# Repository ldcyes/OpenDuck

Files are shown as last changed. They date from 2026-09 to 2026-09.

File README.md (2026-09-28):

# OpenDuck 工程

**简体中文** | [English](README_EN.md)

本仓库整理 Microduck 的结构、电气、步态数值验证，以及 RK3576 驱动和训练适配源。**当前是工程仿真预发布，尚未通过实物制造与正常步速行走验收。**

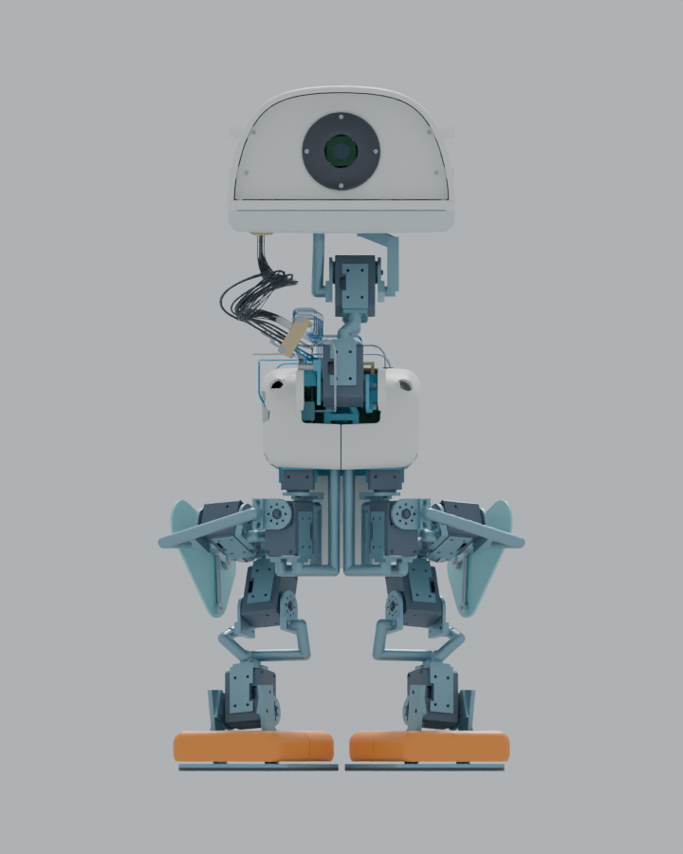
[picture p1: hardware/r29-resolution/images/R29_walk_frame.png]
OpenDuck R29 正视运动模型


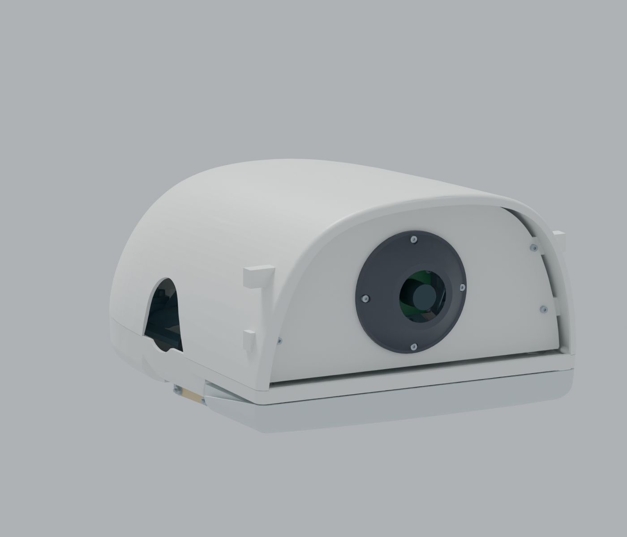
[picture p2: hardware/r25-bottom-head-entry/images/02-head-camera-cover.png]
头部摄像头前盖特写


**本次更新：[R29 干涉、线束与质量重算](hardware/r29-resolution/README.md) · [完整 Blender 与证据下载](https://github.com/ldcyes/OpenDuck/releases/tag/r29-r26-closure-candidate-20260929)。**

R29 将嘴部软件行程收至 0–10° 并修正下头壳；指定腿罩/电机配对在四条新质量慢速轨迹中的最低保守名义间隙下界为 11.407 mm。31 根线的防磨件和四工况动力学已补充，但嘴部闭合扭矩仍超过现行 0.05 Nm 结构限制，连续线束及制造公差尚无实物证明，**不能放行行走**。

沿用R25：31根头部导线改为底部接入，保留前盖与原外形比例；收拢活动线束并取消原侧面专用线孔。[底部走线特写](hardware/r25-bottom-head-entry/images/03-bottom-head-entry.png)。仍为工程候选，离散转头检查不代表连续运动或实物验收。

**历史四步回放：[R27：R26整机运动回放](hardware/r27-walk-replay/README.md)。** 使用已保存的195.44秒实际积分轨迹，逐帧驱动完整R26装配并复核覆盖件的刚体干涉增量；R26质量下的动力学和实物行走仍待验收。

**修复前干涉记录：[R28直接区间检查](hardware/r28-r26-interference/README.md)。** 两块新腿罩在四步轨迹的2,345组动态配对中没有新增穿透；最小保守间隙证明仅0.015 mm，制造公差未通过。旧头壳与嘴部在张嘴约8.75°后仍有真实相交。

**2026-09-24设计复核：[腿部比例与电机筛选](docs/proportion-study-20260924/README.md)。前期比较三种方案，现已采用A修改覆盖件；电机和腿长不变，实物步态未验收。**

[R24摄像头前盖](hardware/r24-head-front/README.md)与历史发布继续保留。

[R23合板支架、线束与热连接](hardware/r23-design/README.md)及其[完整工程](https://github.com/ldcyes/OpenDuck/releases/tag/r23-integrated-power-design-20260922)继续保留。

| 范围 | 早期基线（R23补充见上方入口） | 已有结果与边界 |
|---|---|---|
| 结构与装配 | R20 / R13.7 | 557件，名义质量4.195094 kg；72对参考窄/未证、34对实际名义接口仍保留 |
| 运动 | R21 / R13.8 | 实际身体侧倾与上头壳固定点横摆均减少约28.6%；慢速四步195.44 s；四种数值工况通过，原40%/30%目标未达到 |
| 电气 | R13原生板图 | 12种、13块；原规则DRC为0；额外启用忽略规则仍有43项警告；6块PCB、U2D2及相机待详细安装 |
| 驱动、交互和训练适配 | 已交付R8软件 | 有源码与历史测试；没有RK3576实机运行、GPU训练、实测BAM和批准权重；未完成R20/R21重新适配验收 |

## 从这里开始

- [直接下载完整装配、原始交付包和视频](https://github.com/ldcyes/OpenDuck/releases/tag/r13.8-simulation-20260913)：模型可独立打开；全部大文件保留原始内容，仅采用方便下载的英文文件名。
- [12种KiCad板、原理图及BOM入口](docs/pcb/原生电气设计入口.md)：每板均含项目文件、本地符号库与封装库。
- [PCB功能与主要器件](docs/pcb/01_全部PCB功能与主要器件.md)、[DRC和尺寸结论](docs/pcb/00_PCB检查与缩板结论.md)、[43项警告复核](docs/pcb/02_43项警告逐对象复核.md)。
- [结构修订和完整装配说明](docs/structure-r20/00_修复结果与查看说明.md)、[减摆结果](docs/motion-r21/00_减摆结果与查看说明.md)、[模型与视频查看方法](docs/motion-r21/02_模型与视频查看说明.md)。
- [软件、部署和训练真实入口](docs/software.md)、[复算与来源校验](docs/reproduction.md)、[来源和许可](NOTICE.md)。

## 下载内容

| 文件 | 内容 | 大小（十进制MB） |
|---|---|---:|
| [R13.7结构包](https://github.com/ldcyes/OpenDuck/releases/download/r13.8-simulation-20260913/R13.7-structure-gait.zip) | 结构、图纸、装配模型、沿用源快照和验证结果 | 730.83 |
| [R13.8步态更新包](https://github.com/ldcyes/OpenDuck/releases/download/r13.8-simulation-20260913/R13.8-reduced-sway.zip) | 新步态、四工况结果、减摆对照、更新代码与原始索引 | 603.51 |
| [PCB完整检查包](https://github.com/ldcyes/OpenDuck/releases/download/r13.8-simulation-20260913/PCB-R13-review.zip) | 12种原生板图、BOM、本地库与检查证据 | 1.99 |
| [完整Blender装配](https://github.com/ldcyes/OpenDuck/releases/download/r13.8-simulation-20260913/Microduck-R21-actual-comparison.blend) | 内含全部零件和实际运动，可直接打开 | 66.22 |
| [实际四步视频](https://github.com/ldcyes/OpenDuck/releases/download/r13.8-simulation-20260913/R21-four-steps-24x.mp4) | 约24倍播放速度；原始物理时间195.44 s | 1.14 |
| [同阶段对照视频](https://github.com/ldcyes/OpenDuck/releases/download/r13.8-simulation-20260913/R20-R21-phase-comparison.mp4) | 对齐参考阶段的R20/R21可视化 | 1.45 |

大小和SHA256见 [release-assets.json](release-assets.json) 与 [SHA256SUMS.txt](SHA256SUMS.txt)。GitHub自动生成的“Source code”压缩包只包含本仓库，不包含上述大型交付包。

## 仓库布局

| 目录 | 用途 |
|---|---|
| [hardware/kicad](hardware/kicad) | R13原生板图及本地库，201个文件保留原字节 |
| [docs](docs) | 适合GitHub浏览的说明、图和PCB复核 |
| [software/r8](software/r8) | 已交付R8驱动、交互、训练适配、相机/VLA源码与原验证记录 |
| [reference/work](reference/work) | R20/R21精选原始脚本、核心结果和两版实际轨迹；完整依赖在Release |
| [provenance](provenance) | 原始来源索引、复制哈希和文档路径转换记录 |
| [tools](tools) | 便携的仓库/附件校验和减摆复算入口 |
| [licenses](licenses) | 按来源分别保留的许可及上游说明 |

## 当前限制

正式四步从已经检查的新准备站姿开始；站姿过渡候选没有同等级完整验证。没有完成正常步速、温升、低电量持续扭矩或实物验收，也没有据此放行所有装配间隙。待安装件已有估算质量，实际安装时须替换，不能重复计重。

R8运行时的嘴部限位已按R29改为10°，旧标定/命令绑定会失效；其余硬件、策略及标定仍须重新核准。代码、模拟输入测试和61→14策略接口均不能替代新机械结构的实测标定或批准策略。软件入口默认使用未批准模板或dry-run，当前资料不构成上机运动许可。

项目派生自 Pollen Robotics 的 Microduck。软件、模型、KiCad库和Linux参考源码的许可分别见 [NOTICE.md](NOTICE.md)；本仓库没有给不明第三方资料统一增加商业许可。

## R22 紧凑电源候选（独立预发布）

[R22工程入口](hardware/r22-candidate/README.md)提供新的52×42 mm入口板、舵机电源与回生阶梯合板、原生KiCad/原理图/本地库、Gerber/钻孔和实际安装CAD。本次三个旧板改为两个候选板，总板面积减少14.01%；两块候选的冻结ERC/DRC及额外检查为0。原R13十二种板与R20/R21基线资料继续保留。

新增几何对原R21轨迹关节范围的93,595个动态配对满足≥2.2 mm的保守间隙证据；完整模型为733项装态几何/包络，并非733件制造BOM。这是几何复核，尚未按R22质量重新求解步态，也没有样机制造、温升、回生或行走验收。这些连接在R22交付时未闭合；后续工程设计见[R23入口](hardware/r23-design/README.md)，其物理验收边界另列。

- [R22独立预发布](https://github.com/ldcyes/OpenDuck/releases/tag/r22-compact-power-candidate-20260914)：[完整工程ZIP](https://github.com/ldcyes/OpenDuck/releases/download/r22-compact-power-candidate-20260914/R22-engineering-candidate.zip)、[可独立打开的静态Blender装配](https://github.com/ldcyes/OpenDuck/releases/download/r22-compact-power-candidate-20260914/Microduck-R22-static-candidate.blend)、[两板制造与检查包](https://github.com/ldcyes/OpenDuck/releases/download/r22-compact-power-candidate-20260914/R22-PCB-review.zip)、[SHA256](https://github.com/ldcyes/OpenDuck/releases/download/r22-compact-power-candidate-20260914/SHA256SUMS.txt)。
- [入口板安装](hardware/r22-candidate/mechanics/entry_mount/README.md)、[电容托架最终组合](hardware/r22-candidate/mechanics/motion_delta/CAP_FINAL_SUPPLEMENT.md)、[制造与验收边界](hardware/r22-candidate/fabrication/README.md)。
- [原始来源映射](provenance/r22-source-mapping.json)、[文档路径转换](provenance/r22-document-path-conversions.json)、[Git副本校验](provenance/r22-publication-file-check.json)、[附件摘要](provenance/r22-release-assets.json)。GitHub自动生成的Source code包不含完整工程ZIP和Blender。

R22没有更新RK3576驱动接口、保护阈值或批准训练权重；软件仍以既有R8真实入口及其未验收范围为准。来源和分别适用的许可继续见[NOTICE](NOTICE.md)。

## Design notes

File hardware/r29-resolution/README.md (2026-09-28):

# R29：R26 装配的干涉与动力学复核

[English](README_EN.md) · [R28 问题记录](../r28-r26-interference/README.md) · [R26 原装配](../r26-cover-first/README.md)

这是**工程候选**，尚无实体样机。R29 选择保持 R26 的 1,224 项装配和 15 个关节，以一件新下头壳和四片 PEEK 出线防磨唇边替换五件旧件；腿罩、电机、原 6061 线束桥和安装坐标不变。[完整替换清单](verification/assembly_selection.json)与[源文件哈希映射](../../provenance/r29-source-mapping.json)可供逐项核对。[可交互的完整 Blender 模型](https://github.com/ldcyes/OpenDuck/releases/download/r29-r26-closure-candidate-20260929/OpenDuck-R29-R26-mass-motion.blend)包含静态装配及按 R29 估算质量重新积分的四步回放；[回读记录](verification/blender_readback.json)核对了 1,224 件、五件新网格以及动画首尾姿态。

R29 四步模型画面

| 问题 | 本次结果 | 尚未证明的条件 |
|---|---|---|
| 右大腿罩与左踝电机 | 在 R29 质量重算的四个慢速数值工况中，指定配对的保守名义间隙下界分别为 **11.7228 / 11.6690 / 11.7172 / 11.4071 mm**；每个工况的 9,773 个输出区间均由 12 张证书覆盖。[名义证书](verification/cover_motor_r29_final_10mm_certificate.json)及[四工况分配表](verification/cover_clearance_acceptance.md) | 分配的 6.0 mm 制造/安装/受载闭合预算未经首件测量。若每项均达标，四工况最坏剩余下界 **5.4071 mm**，高于 2.2 mm 目标。此证明只限该配对及所列四条慢速轨迹；[分配表](verification/cover_clearance_acceptance.md)不是整机无干涉证书。 |
| 下头壳与嘴部载体 | 旧件约 8.75° 开始真实穿透。新 PA12 [3MF 打印母版](mechanics/R29_lower_head_shell_mouth_10deg_3mm.3mf)和运行时 0–10° 限位给出**名义连续角域 ≥3.0581 mm** 的保守下界；[扫掠和安装复核](verification/FINAL_MOUTH_REVIEW.md)未见新增 HOME 刚体穿透。 | 对 2.2 mm 制造目标只剩 **0.8581 mm** 总闭合预算；机械硬止挡、实际过冲、螺母座载荷和公差堆栈均未验证。旧 12° 指令/标定已由 [RK 运行时](../../software/r8/rk_runtime/microduck_rk/motion_limits.py)拒绝。 |
| 31 根活动颈部线束 | 四片 [PEEK 唇边](verification/WEAR_LIP_REVIEW.md)各覆盖金属桥出线口外 1.5 mm。九个原姿态的 1,116 组唇边/线材与 42,804 组唇边/刚体筛查未见新增穿透；对 81 个组合端点姿态均进行有界求解，其中 **59 个**得到完整线形并通过 111,125 组近邻实体筛查。 | **22 个组合姿态仍未解**；最小已拟合线间距仅 **0.0161 mm**。59 个线形只是几何见证，未证明真实弹性平衡、连续过渡、磨损或 5 N 夹持。[81 姿态报告](verification/COMBINED81_REVIEW.md)与[验收步骤](verification/HARNESS_REVIEW.md)列出限制。 |
| R26/R29 行走动力学 | 按 R26 原质量 **4.443060 kg**及最终 R29 五件替换后估算质量 **4.442729 kg**，分别重算名义、半步长、μ=0.5 和九接触点四工况。R29 数值轨迹持续 **195.44 s**，双脚各前进两步，身体滚转峰峰值约 **33.38°**；足中段 20–80% 未见 >2 N 接触。[汇总](verification/R29_dynamics_validation.json)与[摆脚接触审计](verification/swing_contact_audit.json)保留全结果。 | 数值步数/轨迹阈值通过**不等于现行整机控制约束通过**。左髋横滚峰值 **0.85955 Nm**，对未实测的 0.9 Nm 上限仅有 **4.49%** 余量；15% 目标要求低电量 10.30–10.35 V、40°C、7,200 s 实测持续能力至少 **1.01124 Nm**。右髋横滚、右膝、左髋俯仰也需要相应实测能力。 |

**当前运行阻断：**现行 RK 软件嘴部结构扭矩上限为 **0.05 Nm**，而 R29 数值模型在闭嘴保持时约需 **0.0567 Nm RMS**，四工况峰值最高约 **0.05925 Nm**。MuJoCo 曾以 0.08 Nm 假设上限完成轨迹，这不能作为现行 0.05 Nm 结构限值的通过证明。必须经明确的减矩/承载结构设计与复算解决，或把嘴部锁定并重新验证；不得直接放大软件限值。[双扭簧解析与线圈空间研究](studies/mouth-counterbalance/README.md)显示潜在减矩路径，但完整弹簧腿、固定点和受力安装尚未设计放行，也**没有**装入本版装配。

制造与实物验收顺序：先按源文件哈希制造并扫描 3MF 下头壳与四片 STEP PEEK 唇边，测装配/受载/温度的实际间隙和嘴部过冲；逐根核对 31 根线的长度、绝缘、夹持、弯曲及 81 姿态连续运动，完成 10,000 次初始循环；在限流台架测嘴部及腿部电机低电量持续扭矩；然后吊架标定、受载测试，最后才进行地面步行。任一门槛失败就修改设计并重新复算。R29 没有制造、样机上电或实物行走批准。

下载：[R29 工程与证据包](https://github.com/ldcyes/OpenDuck/releases/download/r29-r26-closure-candidate-20260929/R29-engineering-evidence.zip) · [完整 Blender 模型](https://github.com/ldcyes/OpenDuck/releases/download/r29-r26-closure-candidate-20260929/OpenDuck-R29-R26-mass-motion.blend) · [SHA256](https://github.com/ldcyes/OpenDuck/releases/download/r29-r26-closure-candidate-20260929/SHA256SUMS.txt)。历史 R28 报告仍描述**修复前**的 R26/R25 几何，不应和 R29 新件混用。

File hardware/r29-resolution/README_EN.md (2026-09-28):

# R29: R26 assembly interference and dynamics review

[简体中文](README.md) · [R28 findings](../r28-r26-interference/README_EN.md) · [R26 assembly](../r26-cover-first/README_EN.md)

R29 is an **engineering candidate without a built prototype**. It keeps the R26 assembly's 1,224 installed items and 15 joints, replacing one lower head shell and four PEEK wire-exit films. The thigh covers, motors, aluminium harness bridges and mounting transforms stay in place. The [complete selection](verification/assembly_selection.json) and [source-hash mapping](../../provenance/r29-source-mapping.json) identify the files. The [standalone Blender assembly](https://github.com/ldcyes/OpenDuck/releases/download/r29-r26-closure-candidate-20260929/OpenDuck-R29-R26-mass-motion.blend) includes a replay of the four-step simulation recalculated with R29 estimated mass; its [readback](verification/blender_readback.json) checks 1,224 parts, the five changed meshes, and the first and last animated poses.

R29 four-step model

| Issue | R29 result | Remaining acceptance work |
|---|---|---|
| Right thigh cover vs left ankle motor | For the four R29-mass slow numerical cases, this pair has conservative nominal clearance bounds of **11.7228 / 11.6690 / 11.7172 / 11.4071 mm**. Twelve certificates cover the 9,773 output intervals in each case. [Nominal certificate](verification/cover_motor_r29_final_10mm_certificate.json) and [four-case budget](verification/cover_clearance_acceptance.md). | A 6.0 mm closing-error budget for fabrication, mounting and loaded deflection is a design allocation, not a measurement. If every allocation is met, the worst four-case bound is **5.4071 mm**, above the 2.2 mm target. This proof applies **only to this pair and the four tested slow trajectories**; see the [budget](verification/cover_clearance_acceptance.md). |
| Lower head shell vs mouth carrier | The former parts penetrate from about 8.75° opening. The revised [PA12 3MF manufacturing master](mechanics/R29_lower_head_shell_mouth_10deg_3mm.3mf) and a 0–10° software limit provide a conservative **3.0581 mm nominal bound throughout the angle range**. [Sweep and mount review](verification/FINAL_MOUTH_REVIEW.md). | Only **0.8581 mm** remains between that nominal bound and the 2.2 mm as-built target. The mechanical end stop, overtravel, nut-boss strength and real tolerance stack are unverified. The [RK runtime](../../software/r8/rk_runtime/microduck_rk/motion_limits.py) now rejects the old 12° command and calibration range. |
| 31 free neck wires | Four replaceable [PEEK wear lips](verification/WEAR_LIP_REVIEW.md) extend 1.5 mm beyond the metal bridge exits. The original nine fitted poses showed no new intersection in 1,116 lip/wire and 42,804 lip/rigid broad checks. Bounded searches attempted all 81 combined endpoints; **59** have complete geometric routes and passed 111,125 nearby body checks. | **22 combined poses remain unresolved**. The closest fitted wire pair is only **0.0161 mm** apart. The 59 routes are geometric witnesses, not measured elastic equilibria; continuous transitions, abrasion and retention remain untested. See the [81-pose report](verification/COMBINED81_REVIEW.md) and [first-article plan](verification/HARNESS_REVIEW.md). |
| R26/R29 walking dynamics | The original R26 estimated mass is **4.443060 kg**; the final R29 five-part assembly is **4.442729 kg**. Nominal, half-time-step, μ=0.5 and nine-contact-point cases were recalculated for both. The R29 nominal sequence lasts **195.44 s**, records two forward steps per foot and about **33.38° peak-to-peak body roll**. The central 20–80% of each planned swing has no sampled contact above 2 N. [Summary](verification/R29_dynamics_validation.json) and [contact audit](verification/swing_contact_audit.json). | Passing numerical step and tracking criteria **does not satisfy the current robot's limits**. Left hip roll peaks at **0.85955 Nm**, only **4.49%** below an unmeasured 0.9 Nm design cap. A 15% margin needs at least **1.01124 Nm measured sustained torque** at 10.30–10.35 V, 40°C for 7,200 s. Right hip roll, right knee and left hip pitch need their own qualification. |

**Active motion blocker:** the RK runtime's mouth structural limit is **0.05 Nm**, while the R29 model needs about **0.0567 Nm RMS to hold the mouth closed** and reaches about **0.05925 Nm** across the four numerical cases. The MuJoCo model used a provisional 0.08 Nm cap, so its completed path is not a pass against the active structural limit. A concrete counterbalance/load-path revision and rerun, or a locked-mouth configuration with its own validation, is required. The software limit must not simply be raised. An optional [dual-torsion-spring calculation and coil-space study](studies/mouth-counterbalance/README.md) suggests a reduction path, but the spring legs, anchors and load-bearing installation are not designed or installed in this release.

For fabrication, use the hashed 3MF head shell and STEP PEEK lips, then scan the assembled and loaded clearances and measure mouth overtravel. Verify each of the 31 wire lengths, insulation, 5 N retention, bend radius and continuous motion through the 81 combined head poses; run an initial 10,000-cycle inspection. Measure sustained low-battery actuator capability on a current-limited bench before supported calibration, load tests and floor walking. A failed gate requires revision and re-analysis. R29 grants no manufacturing or physical-walking approval.

Downloads: [engineering evidence](https://github.com/ldcyes/OpenDuck/releases/download/r29-r26-closure-candidate-20260929/R29-engineering-evidence.zip) · [complete Blender assembly](https://github.com/ldcyes/OpenDuck/releases/download/r29-r26-closure-candidate-20260929/OpenDuck-R29-R26-mass-motion.blend) · [SHA256](https://github.com/ldcyes/OpenDuck/releases/download/r29-r26-closure-candidate-20260929/SHA256SUMS.txt). The historical R28 report describes the **pre-revision** R26/R25 geometry; do not mix its parts into this assembly.

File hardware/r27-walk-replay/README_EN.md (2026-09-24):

# OpenDuck R27: four-step R26 motion replay

[简体中文](README.md) · [R26 covers and complete static assembly](../r26-cover-first/README_EN.md)

This release drives the complete R26 assembly with the recorded R21 free-base numerical trajectory: 195.44175 seconds, four steps and 9,774 saved poses. The Blender scene contains 1,224 selectable assembly geometry entries. The video shows the motion at about 24× speed. **This is a motion replay on R26 geometry; dynamics were not re-solved for R26 mass.**

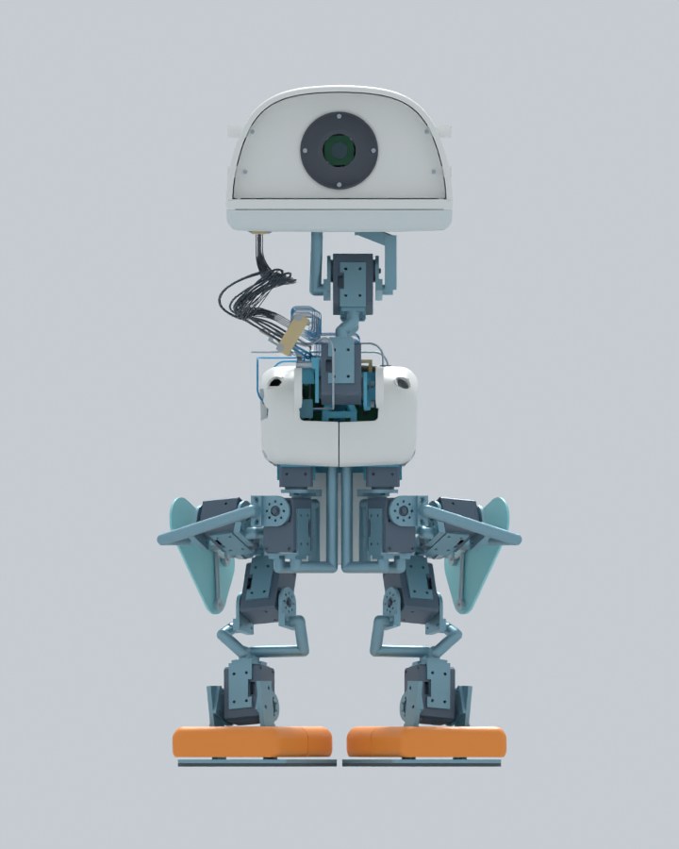
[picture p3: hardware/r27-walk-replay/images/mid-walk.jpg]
Mid-walk pose


[Interactive Blender](https://github.com/ldcyes/OpenDuck/releases/download/r27-r26-four-step-replay-20260925/OpenDuck-R27-R26-four-step-replay.blend) · [Four-step video](https://github.com/ldcyes/OpenDuck/releases/download/r27-r26-four-step-replay-20260925/OpenDuck-R27-R26-four-step-preview.mp4) · [Engineering evidence](https://github.com/ldcyes/OpenDuck/releases/download/r27-r26-four-step-replay-20260925/R27-walk-replay-evidence.zip) · [SHA256](https://github.com/ldcyes/OpenDuck/releases/download/r27-r26-four-step-replay-20260925/SHA256SUMS.txt)

In Blender, select scene `07_R27_R26四步运动回放` and play or scrub the timeline. The original R26 static and comparison scenes remain available. The replay uses recorded free-base and 15-joint states.

The two R26 covers were subsequently checked directly over the integration intervals. See the [R28 interference review](../r28-r26-interference/README_EN.md). Its smallest conservative clearance bound is only 0.015 mm and does not meet the 2.2 mm manufacturing target.

Both new R26 thigh-cover STEP solids are subsets of the old covers. The earlier continuous rigid-body check covered 57 dynamic pairs per old cover across 9,773 integration intervals, with no unresolved dynamic penetration for those pairs. The other 1,191 rigid parts and joint transforms are unchanged. Thus the same trajectory cannot introduce a new rigid intersection through the shortened covers. The 110 named inherited installation contacts retain their individual classification; this does not prove the robot is free of conflicts in all poses.

The 31 free-neck harness pieces were excluded from that rigid interval check. Their movement in this video is a display approximation and cannot establish flexing-wire clearance. The existing mouth/lower-shell conflict beginning around 8.75° remains; mouth command is 0° in this four-step trace.

The R21 dynamics model mass was 4.195094 kg, while the R26 structure estimate is 4.443060 kg, a difference of about 247.97 g. Previous contact, torque and stability results do not qualify R26 dynamics. A new solve using measured R26 mass, inertia, battery voltage, flexible wiring and floor contact, followed by bench and physical walking tests, remains necessary. **This release does not authorize powered walking.**

[Trajectory and collision evidence](verification/analysis.json) · [Blender keyframe and position readback](verification/readback.json) · [Build and verification programs](sources)

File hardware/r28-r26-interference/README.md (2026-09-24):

# OpenDuck R28：R26 装配干涉复核

[English](README_EN.md) · [R26 装配](../r26-cover-first/README.md) · [R27 四步回放](../r27-walk-replay/README.md)

[下载检查证据包](https://github.com/ldcyes/OpenDuck/releases/download/r28-r26-interference-20260925/R28-R26-interference-evidence.zip) · [SHA256](https://github.com/ldcyes/OpenDuck/releases/download/r28-r26-interference-20260925/SHA256SUMS.txt)

对 R26 的两块新大腿罩，直接重跑连续区间刚体干涉检查。输入为 R26 的 1,224 项装配选择及 R21 四步数值轨迹的 9,773 个积分区间（195.44175 s）；其中 31 项自由颈部线束不适合刚体模型，刚体选择为 1,193 项。**在这条轨迹的名义刚体几何中，两块新罩没有新增穿透；整机仍不能按此结果放行制造或行走。**

| 核对对象 | 结果 |
|---|---|
| 新罩与所有其它刚体项 | 2,383 对；2,345 对随关节运动，38 对变换不变 |
| 连续区间 | 9,773 个；全部动态配对完成覆盖，未解决动态穿透为 0 |
| 保守证明的最小动态间隙 | **0.015113 mm**，发生在右大腿罩与左踝电机的区间界计算中；低于 2.2 mm 的目标值，不是制造公差通过证明 |
| 六处固定安装接触 | 左右罩各与本侧 CNC 桥鞍座、F1/F2 OD7 垫圈相接。原生 STEP 布尔交集体积均为 **0 mm³**；网格的微小交集为数值误差 |
| 旧件之间 | 原 R25 的 46,170 对动态记录与 110 项命名固定接触沿用；本次没有把全部旧件两两重新计算 |

**保留的真实冲突：**R25 下头壳 `R25_lower_head_shell_bottom_entry` 与嘴部载体 `R12_mouth_load_carrier`，在每 0.25° 的张嘴扫描中首次于 **8.75°** 相交，交集约 **0.1225 mm³**；25° 时约 218.58 mm³。此次四步轨迹的嘴部指令仅约 −0.00154° 至 +0.00264°，所以行走回放没有触发该冲突。嘴部全行程不能验收，需修改几何或限位后重新检查。

这项检查使用保存的 R21 轨迹，动力学质量为 4.195094 kg；R26 估算质量 4.443060 kg，并未按新质量重新积分。0.015 mm 是三角网格保守下界，不包含打印误差、紧固件实际偏心、负载变形、线束柔性、地面接触或电机轴承游隙。现阶段只说明受检轨迹没有**新增的名义刚体穿透**，不能宣称所有姿态、所有零件或实物步行无干涉。

[审核摘要](verification/direct_review.json) · [区间原始结果](verification/result.json) · [配对索引](verification/pair_index.json) · [嘴部扫描](verification/mouth_interference.json) · [输入与检查程序](sources)

复算需使用 R26 工程包及 R21/R25 的原始几何和运动文件，放在与源码记录相同的 `work/` 目录布局。源码中的 SHA256 绑定用于核对输入；本目录的 JSON 记录与对应源码同字节保存。检查不涉及样机上电、受载或实物行走。

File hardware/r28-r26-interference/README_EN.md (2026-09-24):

# OpenDuck R28: R26 assembly interference review

[简体中文](README.md) · [R26 assembly](../r26-cover-first/README_EN.md) · [R27 four-step replay](../r27-walk-replay/README_EN.md)

[Download evidence ZIP](https://github.com/ldcyes/OpenDuck/releases/download/r28-r26-interference-20260925/R28-R26-interference-evidence.zip) · [SHA256](https://github.com/ldcyes/OpenDuck/releases/download/r28-r26-interference-20260925/SHA256SUMS.txt)

The two new R26 thigh covers were checked directly against the recorded 9,773 numerical integration intervals (195.44175 s). The R26 selection contains 1,224 installed geometry entries; 31 flexible neck-harness entries are excluded from rigid-body testing, leaving 1,193 rigid entries. **No new rigid penetration was found for the covers along this nominal trajectory. This does not approve fabrication or physical walking.**

| Check | Result |
|---|---|
| New covers versus other rigid entries | 2,383 pairs: 2,345 moving and 38 invariant |
| Continuous intervals | All 9,773 intervals covered for every moving pair; zero unresolved dynamic penetrations |
| Smallest conservative moving-pair clearance bound | **0.015113 mm**, for the right thigh cover versus the left ankle motor. This falls below the 2.2 mm target and does not establish a manufacturing tolerance margin. |
| Six fixed seating contacts | Each cover meets its own CNC bridge saddle and F1/F2 OD7 washers. Native STEP Boolean intersection volume is **0 mm³** for all six; tiny mesh intersections are numerical error. |
| Old-to-old pairs | The prior R25 ledger of 46,170 dynamic pairs and 110 named invariant contacts is inherited; old-to-old geometry was not recomputed in this direct check. |

**Existing real interference remains:** the R25 lower head shell intersects the R12 mouth carrier when opening. A 0.25° sweep first found intersection at **8.75°** (about **0.1225 mm³**); at 25° it reaches about **218.58 mm³**. The recorded four-step mouth command stays near zero (−0.00154° to +0.00264°), so this gait does not exercise the conflict. Full mouth travel requires a geometry or limit correction and another check.

The trajectory was integrated for R21 at 4.195094 kg; the R26 estimate is 4.443060 kg, and R26 dynamics have not been recomputed. The 0.015 mm bound applies to nominal triangulated rigid geometry, without print tolerance, fastener eccentricity, load deformation, flexible harness motion, ground contact or bearing play. This finding is limited to **new nominal rigid intersections on the checked trajectory**.

[Reviewed summary](verification/direct_review.json) · [interval result](verification/result.json) · [pair index](verification/pair_index.json) · [mouth sweep](verification/mouth_interference.json) · [inputs and checkers](sources)

Reproduction needs the original R26, R25 and R21 engineering geometry and motion sources in their recorded `work/` layout. Source SHA256 bindings are retained. No physical power-on, load or walking test was performed.

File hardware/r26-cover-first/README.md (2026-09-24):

# OpenDuck R26：A方案大腿覆盖件

[English](README_EN.md) · [Blender](https://github.com/ldcyes/OpenDuck/releases/download/r26-cover-first-20260924/OpenDuck-R26-cover-first.blend) · [ZIP](https://github.com/ldcyes/OpenDuck/releases/download/r26-cover-first-20260924/R26-cover-first-design.zip) · [SHA256](https://github.com/ldcyes/OpenDuck/releases/download/r26-cover-first-20260924/SHA256SUMS.txt)

按已选A方案，缩短两侧大腿罩下缘，保持实际腿长、15个关节、商品电机、支架及固定五金的位置。**工程候选，未制造或实物验收。**

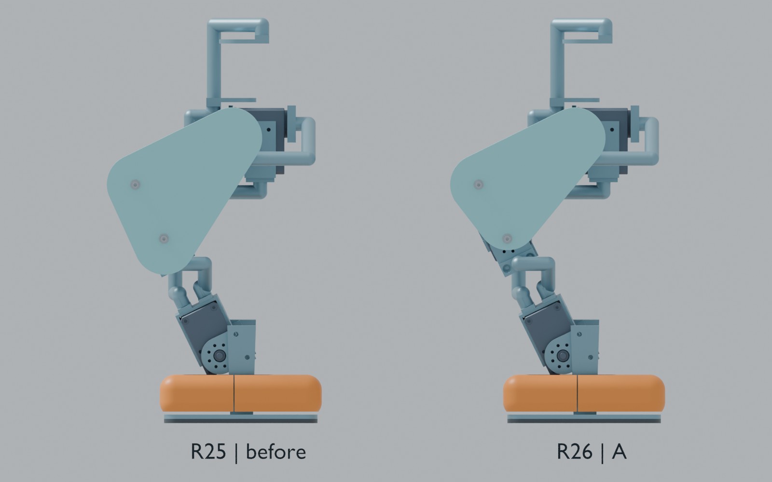
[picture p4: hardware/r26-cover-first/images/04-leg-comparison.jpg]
大腿覆盖件同尺度对比


下缘从膝轴下约27.23 mm收至10.00 mm，恢复约**17.23 mm**垂直露出量。2 mm主壁、两个安装孔、定位沉孔和OD9垫圈承压台保留；固定孔中心到新外缘最小**8.056 mm**。新零件是原覆盖件的实体子集，四处工具外伸通道已检查。此处不将孔边距和主壁数值称为已通过实物受载验证。

## 下载与装配

- [两件打印主文件3MF](print)、[原生STEP](step)、[STL毫米](stl)、[轮廓尺寸PDF](documents/R26-cover-profile.pdf)。3MF是打印主文件；STEP用于原生实体核对。STL没有内置单位，导入必须选毫米，禁止自动缩放。
- 完整Blender可独立打开：场景01完整R26，02/03为同尺度新旧比较，04/05保留R25头部细节，06保留原R25参考。完整装配仍有1224项几何和17项隐藏服务参考，不能等同制造BOM零件数。Outliner可逐件选择、隐藏PCB、电机和结构。
- 装配仅替换原`R18P_L/R_thigh_photo_triangle`两件。既有支架不拆改；在无载台架、断电状态下，先卸外侧两颗M2.5×8螺钉与OD7垫圈，再沿各侧向外法线脱离定位凸台。新罩对准原定位点，依原顺序放回垫圈和螺钉。实际紧固扭矩、打印孔径/收缩与夹持力仍须首件确认；不在本次新增未经来源验证的紧固扭矩。
- ZIP是工程增量：叠加R23/R24/R25完整工程到相同根目录；执行入口位于`work/r26-cover-first/`。单独Blender和本目录的STEP/3MF不依赖旧工程才能打开。

## 已完成的检查

- 新旧原生实体、STEP在独立进程读取后的差分，以及独立网格核对均有记录。共面构造首次暴露出跨进程布尔异常，现已通过仅修改裁切工具消除；重新读取原始STEP后验证，未通过放宽体积阈值绕过。
- 两个新件原生实体有效、单实体；导出网格闭合、定向一致。完整固定支承R7区域、OD9承压台及沉孔区域均无丢失材料。打印格式回读与体积/包络误差有逐项记录。
- 对每个新罩筛查全部其它1223项所选几何，精查12个邻近配对。名义安装面接触按具体配对记录。工具通道是最终装盖阶段直径3 mm、外伸35 mm的杆部空间；不包含真实手柄、握持或批头配合的实物认证。
- 两盖原生实体子集、其所属连杆变换不变，其它部件不变，因此在相同关节姿态下不会新增刚体相交。这是连续姿态的**碰撞增量证明**，不是整机旧冲突已消除，也不代表载荷变形、制造公差、实际线束运动或真实步态通过。
- 1222项保留装配记录及15个关节记录未变。完整Blender另经新进程回读，核对真实来源、坐标与替换关系。

## 质量、侧向内收与边界

两盖合计减重约**4.420 g**；整机工程估计质量**4.443060 kg**。HOME重心变化约(+0.0337, -0.0016, +0.1428) mm。原质量账扣除两盖一次，新盖计入一次。这是材料密度估计，不是称重结果；不据此宣称动态平衡改善。

本次没有实施4 mm侧向内收：原定位凸台只进入0.8 mm，直接内移会改变支承面及螺钉堆叠，需要另做桥架结构。保持原安装面完成下缘优化，不增加连杆力臂或整体高度。模型HOME高约570.393 mm；不同站姿高度随关节角变化。

头部左侧开孔永久闭合B方案仍待独立实施，本R26仍保留R25头壳，不能据新腿图认为头孔已封。R25旧下壳与嘴部约8.75°起的冲突、线束离散姿态/公差限制、低电量持续扭矩、热、续航与实物行走未验收项继续保留。**不发布新电机采购定型、训练权重或装机运动许可。**

## 证据

[原生几何与打印回读](verification/geometry_checks.json) · [整机与工具/碰撞增量](verification/verification.json) · [质量重心](verification/mass_delta.json) · [Blender回读](verification/Blender-readback.json) · [制造及验证源程序](sources)

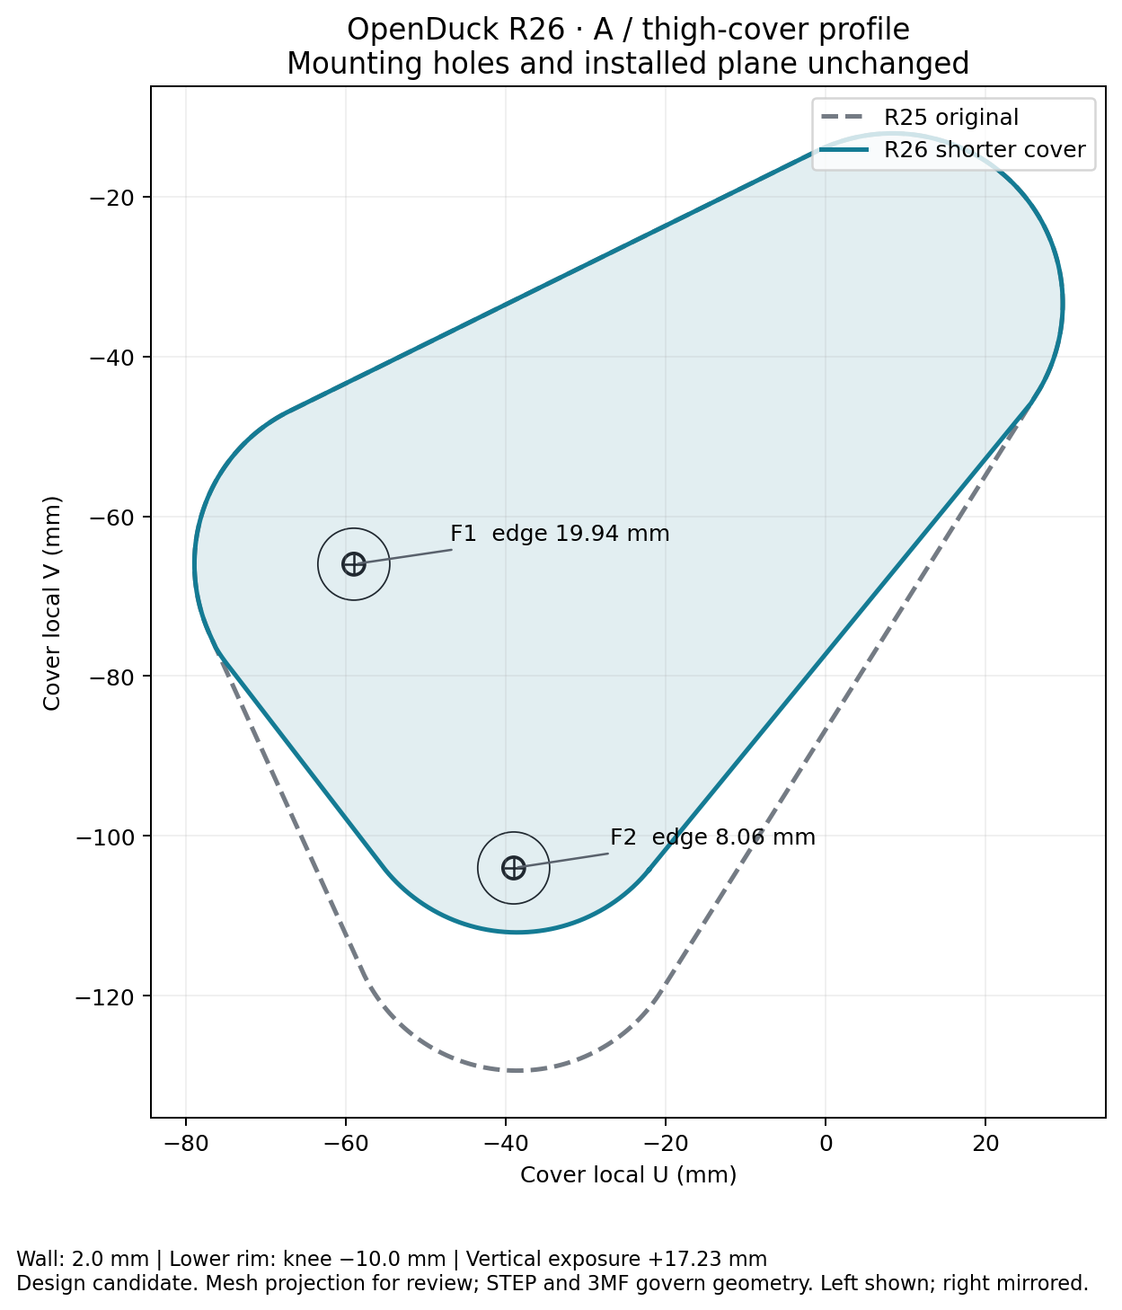
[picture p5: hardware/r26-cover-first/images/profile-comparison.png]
新轮廓与固定孔


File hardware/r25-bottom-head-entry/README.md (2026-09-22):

# OpenDuck R25：头部底部接线

头部前盖

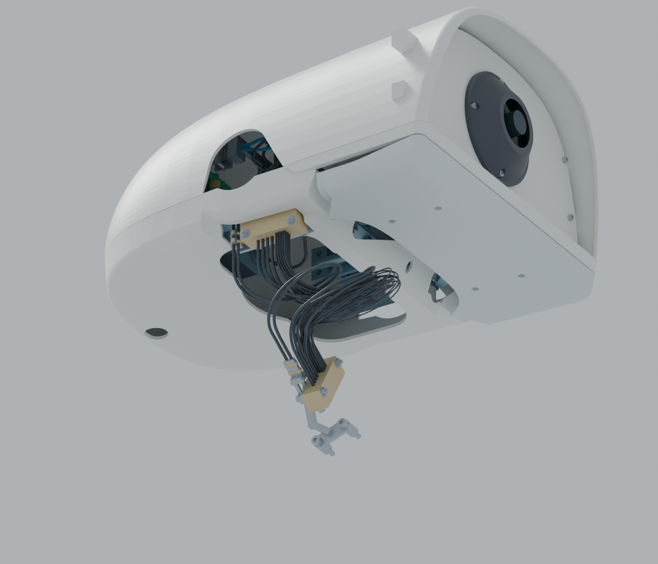
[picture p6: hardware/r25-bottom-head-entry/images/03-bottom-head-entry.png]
底部导向和收拢线束


[完整R25 Blender](https://github.com/ldcyes/OpenDuck/releases/download/r25-bottom-head-entry-20260923/OpenDuck-R25-bottom-head-entry.blend) · [工程增量ZIP](https://github.com/ldcyes/OpenDuck/releases/download/r25-bottom-head-entry-20260923/R25-bottom-head-entry-design.zip) · [尺寸与装配图](documents/dimensions-and-assembly.pdf) · [两件打印主文件](print) · [桥架STEP](machining/bottom-entry-bridge.step)

ZIP叠加[R23工程](https://github.com/ldcyes/OpenDuck/releases/tag/r23-integrated-power-design-20260922)和[R24工程](https://github.com/ldcyes/OpenDuck/releases/tag/r24-head-camera-cover-20260923)使用；Blender可独立打开。下文相对路径对应ZIP工程根目录。

本版将31根跨颈部导线从头部侧面入口改为底部入口，保留R24摄像头前盖及整机比例。上头壳恢复原型侧面壳面，原有电机工作孔保留；该孔不再作为线束入口。当前为工程设计候选，未制造、未上电、未放行运动。

## 实际改动

- 新上、下头壳：上壳关闭旧31线专用窗口，保留R24四个前盖安装耳；下壳新增底部导向孔和桥架让位口。两件均提供毫米单位3MF打印主文件及双精度PLY，经过拓扑与坐标回读。
- 上导向座：自由出口基准为HOME坐标 **(32, −68, 198) mm**，固定侧朝+Z、自由侧朝−Z。PEEK梳形孔、VMQ夹持件、压盖、P5/P6衬片及绑带整体重新定向。
- 新6061桥架：保留原头内承载梁夹座、17mm孔距、M2紧固件及原正向限位环，重新设计绕过承载板、螺钉和线束的连接臂。下导向座位置不变。
- 31根头内固定尾线：重新布置入口段，保留原电气端点、端子定义和原有末端细节；P1–P4的剥线/焊接材料边界保留，不用整根绝缘圆管代替焊点。
- 31根活动线：采用统一缩短到旧长度82%的收拢方案，自由段约200–223mm，两根P5/P6电源线并入主束旁。HOME横向范围由保守长线方案约171mm缩至106mm；保留导线身份、端点和物理长度约束。模型里是HOME形状，不刚性绑定到头部，也不代表布线动力学仿真。端点、物理长度与导向内部长度归属集中见`routing_contract.json`。

## 文件与查看

`visual/OpenDuck_R25_底部走线.blend` 是完整装配，能够独立打开。场景01为整机、02为摄像头前盖、03为底部接线；在Outliner中逐件选择/隐藏。显示颜色是部件识别色，实际线色仍按端号表。服务参考默认隐藏且不重复计重。

所选活动线唯一入口为`flex/compact_bundle_home/manifest.json`；`flex/selected_home`、`home_geometry`及其他候选仅为过程对照，不得混装。

`assembly_selection.json` 是装配选择清单；`mechanics/manifest.json`、`tails/manifest.json`及所选自由线路清单指定零件来源。不要混用早期诊断线束，尤其不能用只按HOME最短路径生成的长度剪线。`R25_头部底部入口与装配.pdf`给出入口、固定接口和装配顺序；`Complete_Conductor_Lengths_R25.json` / CSV保留59线总表，31条随新走线更新，仍为未放行的裁线候选。

本增量包叠加R23完整工程与R24前盖工程使用，所有路径相对于同一个工程根目录。Blender不需要这些外部依赖。R23/R24历史包不改写。

## 已核查的范围

- 静态使用全部新实体和全部保留装配实体，包含完整自由线束与固定尾线。螺纹接合、软夹持面和绑带结头按具体配对记录；部分三角网格接触通过原生STEP二次核实，不能将所有重叠统一忽略。
- 新刚体对记录步态的66,348个配对、9,773个关节区间进行了检查，其中46,170个动态配对没有未解决项。该轨迹中头部变化很小，不能代替大角度转头；自由线束不参与刚体绑定检查。
- 新导向/桥架/固定尾线对嘴部0–25°几何扫掠的连续间距下界为4.719mm。整机旧下壳在约8.75°开始与旧嘴部承载件相交，另有旧壳/嘴窄间隙未获连续裕量；本版没有批准25°嘴部工作行程。
- 工具通道以明确的装配阶段检查：先在台架上穿入直线、未端接的导线，紧固压盖，再成型和端接；导向座及桥架在头部连接颈部、安装上下壳之前固定。不能在整机闭壳后照搬这些工具通道结论。
- 最终短线按HOME及颈俯仰±10°、头俯仰±15°、偏航±30°、侧倾±10°的单轴端点逐一检查，嘴保持0°；这是9个离散姿态，不等于同时组合四轴、姿态之间连续变形或真实弹性平衡的证明。全族最小名义线间距下界仅约0.0161mm、最大长度残差约0.00265mm；前者不足以作为制造公差裕量，必须在实物夹持、线束回弹和磨损试验后重新定型。
- 单件STEP有效性、打印3MF/PLY的单实体闭合拓扑、完整Blender逐件坐标和来源均回读检查。详细数据和最终自由线姿态范围见`delivery_verification.json`及其引用报告。

## 首件仍需验证

密集导线的名义间距不等于制造裕量。须实际测量夹持、摩擦、反复转头磨损和温升，逐线核对端号与线长。沿用单根5N、同一时刻总束不超过5N的拉力验证方案；滑移≤0.2mm且绝缘无损。实际材料、加工公差、夹紧力与导线回弹必须由首件确认。

本版没有重新批准整机扭矩、续航、正常步速行走、相机实际图像或训练策略；R23的温升测点、旧电机接口、低电量持续驱动及动态平衡未闭合项继续保留。质量为材料和最大线密度工程估计，不是实测称重。本版约4.447479kg，相对R24净增约0.170g，HOME重心变化约(−0.112,+0.133,−0.225)mm；不据此宣称动态平衡已经验证。

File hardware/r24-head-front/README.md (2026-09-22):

# R24 · Microduck 风格头部摄像头前盖

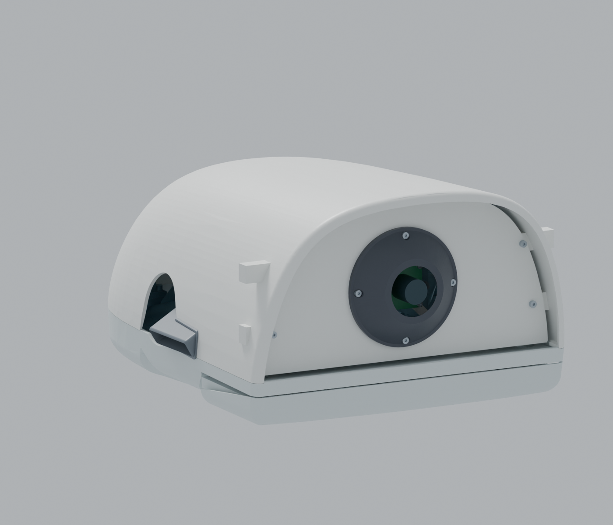
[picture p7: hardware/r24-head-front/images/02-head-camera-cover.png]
R24头部摄像头前盖


[完整R24 Blender模型](https://github.com/ldcyes/OpenDuck/releases/download/r24-head-camera-cover-20260923/Microduck-R24-head-camera-cover.blend) · [R24工程增量包](https://github.com/ldcyes/OpenDuck/releases/download/r24-head-camera-cover-20260923/R24-head-camera-cover-design.zip) · [3页尺寸与装配图](documents/dimensions-and-assembly.pdf) · [BOM](documents/BOM.csv)

打印主文件：[前盖与相机支架](print/front-face-camera-carrier.3mf)、[黑色镜头圈](print/black-camera-eye-bezel.3mf)、[新版上头壳](print/top-head-shell-with-lugs.3mf)。各1件，原始编号与摘要见[来源映射](source-mapping.json)。只有这3件为打印交付物。

下文中的原始文件路径对应工程ZIP；源码复算需[R23完整工程](https://github.com/ldcyes/OpenDuck/releases/tag/r23-integrated-power-design-20260922)。Blender模型可以独立打开。相机线缆末端和首件验收未闭合，因此仍是预发布。

在 R23 整机上增加可拆前盖、黑色镜头圈、相机背部支座与四个头壳安装耳。前脸沿用原 Microduck 的轮廓，保留本项目已采用的 R0×2.1 比例；头部外包络没有整体放大。原未使用的 ToF 位置封闭，不虚构额外传感器。

**这是工程设计候选，尚无实物样机或制造放行。** 摄像头插头和线缆末端、背面支承平整度、镜头入口瞳和实际视野仍须首件核对。R23 的电气、热、实测扭矩和行走未决项继续保留。

## 文件与查看

- `visual/Microduck_R24_摄像头前盖.blend`：完整静态装配，1225项装态几何/包络、17项隐藏服务参考。场景01看整机，场景02看头部；Outliner可逐件选择、隐藏PCB/电机/结构。它不是新行走动画。
- `R24_前盖尺寸与装配.pdf`：3页安装尺寸、剖面、装配顺序和首件验收要求。
- `BOM.csv`：打印件和采购五金的数量、尺寸要求。
- `geometry/`：3MF为三个打印件主文件，PLY为同拓扑分析副本。其余STL是五金/相机包络或耳座审计工具，**不能全部发送打印**。
- `assembly_selection.json`：R24完整装配清单；`manifest.json`说明新增/替换关系及原始来源。
- 各项`*_check*.json`、`contact_review.json`、`mass_delta.json`、`shell_surface_audit.json`保存计算证据和范围。

只打印以下三件，每件1个，建议PA12 SLS：

1. `R24_Microduck_front_face_camera_carrier.3mf`：前盖和相机支架一体。
2. `R24_black_camera_eye_bezel.3mf`：黑色镜头圈。
3. `R24_top_head_shell_front_cover_lugs.3mf`：替换R23上头壳，安装耳已连成一个实体。

摄像头仍是 Waveshare OS05A10 5MP USB Camera(A)，SKU33123。供应商给出的25×25mm、21mm孔距、Ø14镜头等只构成尺寸包络，不代表已拿到完整供应商CAD。四颗M1.6×14穿过四个安装孔；须核对背面支承区是否有元件，不得用螺钉把板强行压平。没有新增光学玻璃。

## 检查结果与边界

- 新增37项、替换旧上头壳1项，保留1188项。对完整1225项装态模型进行44,622个新增相关静态配对筛查；31条软线束仅为HOME姿态，不代表实际弯曲。
- 原步态9773个记录区间中的43,475个刚体配对已完成检查，包括29,970个动态配对；没有动态未证配对。32对同刚体装配贴合和12对螺纹表示逐对记录。此检查证明指定轨迹的名义几何分离，**不表示所有间隙达到2.2mm或实物行走通过**。
- 独立检查嘴部0–25°：新增前盖/耳座/五金对5个嘴部实体共200对，采用采样距离扣除连续旋转位移上界，最低名义连续间隙下界4.7496mm。旧壳与旧嘴之间的约1.4mm间隙未因此解决；该角度也不是电机软件限位批准。
- 前盖下沿和边缘已修整：发现的“装好不撞、向前抽出却卡壳”已消除。拆下4颗前盖螺钉、断开USB后，检查0–40mm向前抽出路径；实际插头及线缆操作仍待核对。
- 96°是**对角**视场。按50°半角、入口瞳后退4mm、轴向公差0.4mm和偏心0.5mm的假设进行包络检查，无壳体遮挡。真实入口瞳与画面边角须实测，不能直接保证无暗角。
- 12处正面驱动工具通道已检查；相机应先安装在拆下的前盖上，再装黑色镜头圈。裸上头壳先侧装M2螺母，然后装其余头部组件。后侧反扳工具和完整相机插拔动作仍需首件试装。
- 原上头壳的共面三维布尔差集出现负体积，未将其裁零或作为零切除证据。独立以保留三角面、双向平面多边形覆盖核对：四个声明耳座区域之外的表面保持一致，最大未覆盖残差小于0.000001mm²（平面距离容差0.00001mm）。详见`audit_shell.py`及报告。
- 三个打印主文件均单体、闭合、绕向一致；3MF/PLY读回的顶点与拓扑一致。保存后的Blender另行读回，核对1225项装态与17项服务参考的位置及来源。

## 质量与重心

PA12取0.93g/cm³，五金取7.9g/cm³，仅作工程估算。已扣除旧上头壳，沿用原15g“相机及随附线缆”一次，两个相机显示包络不会再重复计重。

最终净增重约47.90g，整机估算4.44731kg；重心相对R23前移约1.45mm、上移约2.67mm。相机/随附线缆重心仍是未实测的分布假设。新增质量产生的俯仰重力矩增量约0.064N·m（HOME参考），**没有重新批准新质量下的电机连续扭矩、步态、平衡或续航**。

## 复算与来源

这是叠加在[R23完整工程](https://github.com/ldcyes/OpenDuck/releases/tag/r23-integrated-power-design-20260922)上的独立修订；原R23发布未修改。完整Blender可直接打开，源码复算需将本包按原路径叠加至R23工程目录。先检查文件SHA256，再运行`build.py`、静态/细节/拆装检查；区间检查调用原R23包装器并使用R24的`rigid_inputs.json`，输出必须新建目录，不能覆盖冻结结果。采用Python、NumPy、trimesh、manifold3d、Matplotlib及Blender4.5；分析坐标单位mm，Blender场景单位m。

打印件由网格源派生，因此交付的是3MF和索引PLY，不冒充参数化STEP实体。原始轮廓、来源清单和供应商尺寸图随包保留。原模型来源是[Pollen Robotics Microduck](https://github.com/pollen-robotics/microduck_rl)固定快照；沿用项目NOTICE及原模型非商业许可限制，不额外授予商业许可。相机尺寸来自[Waveshare官方产品页](https://www.waveshare.com/OS05A10-5MP-USB-Camera-A.htm)。

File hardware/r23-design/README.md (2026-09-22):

# R23 合板主支架、线束与热连接

本次把 R22 紧凑电源板接入现有 RK3576 机器人，补齐主支架、完整端接与固定、风道和导热结构。**工程设计评审预发布；没有样机制造、低电量持续扭矩、温升或行走验收。**

[完整工程 ZIP](https://github.com/ldcyes/OpenDuck/releases/download/r23-integrated-power-design-20260922/R23-engineering-design.zip) · [完整 Blender 模型](https://github.com/ldcyes/OpenDuck/releases/download/r23-integrated-power-design-20260922/Microduck-R23-integrated-design.blend) · [附件 SHA256](https://github.com/ldcyes/OpenDuck/releases/download/r23-integrated-power-design-20260922/SHA256SUMS.txt)

模型包含1189个装配对象和17个非装机工具/自由态参考，可逐件选择、隐藏 PCB、结构、电机和线束。场景01看整机，02看主支架与热连接，03看线束。对象数含子线段和器件包络，不等于制造BOM数量。

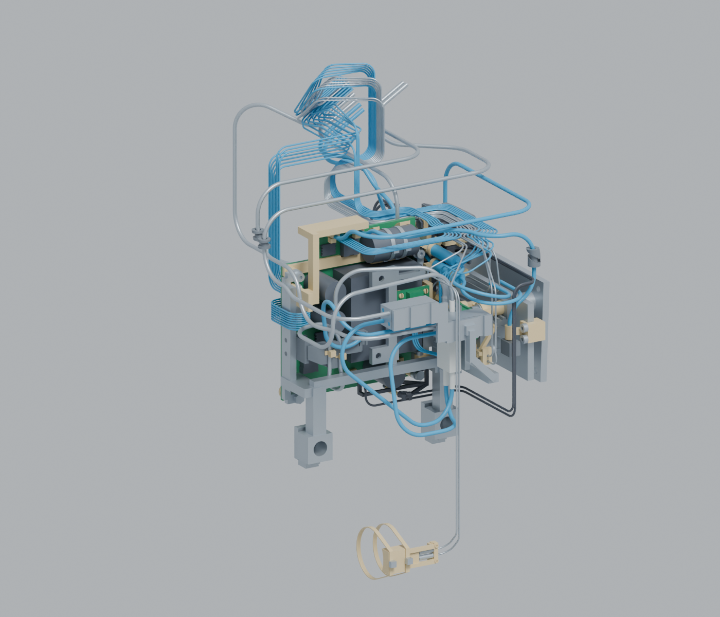
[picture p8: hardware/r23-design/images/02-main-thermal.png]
合板主支架与热连接


## 图册与验证

- [整机预览](images/01-complete-assembly.png)
- [线束预览](images/03-wiring.png)
- [主支架尺寸、截面与载荷图册](documents/main-bracket-dimensions-and-load.pdf)
- [后载体尺寸、安装与工具通道](documents/rear-mount-dimensions-and-assembly.pdf)
- [后载体载荷与预紧条件](documents/rear-mount-load-review.pdf)
- [线束工艺基础图册（改线行以最终补充图页和总表为准）](documents/harness-process-base.pdf)
- [全部装配对象及制造文件索引（路径对应完整 ZIP）](documents/part-catalog.csv)
- [最终59行综合裁线表](documents/complete-conductor-cut-table.csv)
- [改线与综合裁线补充图册](documents/dynamic-wire-corrections-and-cut-table.pdf)
- [H05嘴部避让与补强尺寸图](documents/h05-mouth-relief-dimensions.svg)
- [最终数值勘误与资料优先级](documents/final-errata.md)
- [W1铜损与热预算敏感性](documents/w1-copper-heat-sensitivity.md)
- [最终质量、重心及后载体载荷补充（覆盖旧图册载荷输入）](documents/final-rear-load-rebind.md)

ZIP中保持原始工程路径。唯一当前选择是 `work/r23-power-integration/integration/assembly_selection.json`（SHA256 `a9df66c72faf49bd74b2c5047ffddb117d498ca943c228e131047d6c2ce29ff0`）；历史候选和追溯文件不应叠加制造。网格打印主文件、STEP与逐件资料索引都在完整ZIP中。自由线HOME外形用于查看，按完整裁线表和工装制造。

## 当前结论

- 主支架按230g局部附件上限、上轨200g及规定重心盒检查；后载体采用独立7075适配件、PEEK件和低头螺钉，附装配/工具通道及预紧条件。指定截面计算不替代整件实物受载验证。
- 线束包含59条新增或修改电路、157条端到端关系；其余98条沿用，未宣称重新制作或实测。电芯正极至首保险丝98.473452mm工程预算保留已批准100mm上限及首件验收条件。
- W1、S03回弯及H05嘴部支架已修正；三件对整机其余刚体的2077组动态关系达到2.2mm检查目标。裁线使用最终59行总表和补充图册：W1为129±1mm，S03整根为665±1mm。原14页工艺图册对应旧行已被替代。
- 整体增量动态检查有244493/244494对达到2.2mm；剩余上头壳／嘴托继承表面约1.40mm，仍低于目标。H05与固定cradle的0.502710mm装配缝另有尺寸预算。不能把具名检查推广为整机所有间隙均合格。
- 质量工程场景为4.399406kg，含37.392588g额外线束预留。8399点规定轨迹最大扭矩利用率：静态92.041%、含规定惯性93.214%；最小单脚COP余量7.449/7.245mm。原85%静态利用率和8mm余量目标未恢复，工程限值本身也没有连续电机能力认证。
- 热连接和风道有几何及集中参数计算；四个转换器内部Tc相关参考件仍缺供应商内部尺寸。传感欠读、热态预紧窗口、实际散热和电池1～2小时续航须由样机验证。原30对电机/耳接口的名义未验证边界仍保留。

PCB沿用[R22两板](../r22-candidate/README.md)和其余原板，共11种板型、12块实板（左右LEG5各一块）；本轮没有改PCB走线或新增DRC通过声明。[原生板图](../kicad)、[软件与训练入口](../../docs/software.md)继续保留；没有新批准权重或RK3576实机报告。

[最终评审来源](../../provenance/r23-final-review.json) · [源文件与ZIP映射](../../provenance/r23-source-mapping.json) · [Git副本映射](../../provenance/r23-git-file-map.json) · [附件摘要](../../provenance/r23-release-assets.json) · [来源和分别适用的许可](../../NOTICE.md)

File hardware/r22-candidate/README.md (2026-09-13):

# R22 紧凑电源设计候选

已完成两块实际四层PCB、原理图与本地库、BOM、接口、加工图及配套安装CAD。它们是用于工程审查的R22候选；现行R20结构/R21步态基线保留。没有样机，尚未完成制造、温升、动态回生、低电量及实物行走验收。

| 项目 | 原设计 | R22实际设计 | 面积变化 |
|---|---|---|---:|
| 5V入口板 | 65×45 mm，2925 mm² | 52×42 mm，2184 mm² | −25.33% |
| 舵机电源与回生 | 65×60加32×30 mm，4860 mm² | 阶梯合板，4510 mm²；最大外接65×75 mm | −7.20% |
| 本次三个旧板合计 | 7785 mm² | 两板6694 mm² | −14.01% |

若整机采用此候选，板型由12种减为11种，实际板数由13块减为12块（LEG5仍有左右两块）。这不是整机占用空间或续航同比改善；合板最大75 mm长度必须按阶梯轮廓检查。

## 打开工程与图纸

- [5V入口板说明](entry/README_R22_Entry.md)：打开 `entry/Microduck_Entry_5V_R22.kicad_pro`。58个封装，原159个原理图针与200个数字焊盘实例映射保持；五个SH同系列插头改顶插，保留原线端插壳及线序。
- [舵机电源＋回生说明](power_regen/README.md)：打开 `power_regen/Microduck_Power_Regen_R22.kicad_pro`。84个封装、292个焊盘，三页原理图；只合并SERVO_BUS/GND，其他控制与辅助电源网保持分离。J1改BM08顶插。
- [入口板安装图与STEP](mechanics/entry_mount/README.md)、[回生电容托架最终装配说明](mechanics/motion_delta/CAP_FINAL_SUPPLEMENT.md)。电容保留EEUFR1C222（2200µF/16V），改卧装并独立支承，须先在机外完成成形、固定与焊接。
- `fabrication/entry/`、`fabrication/power_regen/`：从已独立验证的原生副本导出的四层Gerber、正背阻焊/钢网、轮廓与分开的PTH/NPTH钻孔。按[制造与验收边界](fabrication/README.md)审查，不能把文件已生成等同于制造放行。
- 完整Blender和工程ZIP见[OpenDuck的R22预发布](https://github.com/ldcyes/OpenDuck/releases/tag/r22-compact-power-candidate-20260914)。KiCad、本次实际STEP/STL与Blender可分别打开；历史全过程复算仍依赖原R20/R21源快照及其运行库。

## 电气检查与计算的含义

根任务对冻结副本重新执行ERC、铺铜DRC、未连接检查、原理图/PCB一致性检查，并开启原来被忽略的DRC类别，两板结果均为0。独立复核另在副本开启四类默认忽略ERC检查，结果同样为0，见`final_review/supplemental_erc/`。这不等于实机电源合格。证据在 `final_verification/freeze_v1/entry/` 与 `final_verification/freeze_v2/power_regen/`；其他板仍沿用原R13审查结果。

两板均为1.60 mm、70/35/35/70 µm铜的四层结构。线宽≥0.20 mm，铺铜间距≥0.20 mm；入口板4对、合板15对局部逃线间距为0.175 mm，逐项记录。不能把“DRC为0”改写成全板任何间距均≥0.20 mm。孔铜厚度、塞孔填孔/盖铜、叠层与细间距均须由加工厂确认，见两板制造报告。

入口板用实际保存的铜区、走线、焊盘和贯穿孔建立直流电阻网格；含地回流的MOBILE与BENCH路径估计分别较原板降低50.67%与47.01%。这是数值铜路估算，源端/负载端焊点、线束、接头和动态纹波另计。保守设计预算下2.7 A板端约4.835 V仍未扣纹波与外部线损，不是整机满载验收值。

合板所选回生板内铜回路约4.866 mΩ@20°C；条件12.121 A时约59 mV、0.715 W。原两板纯板内铜约3.043 mΩ但不含删除的板间正负线对与接点，不能单凭合板宣称总回路降阻。12个换层孔的最大估计分流约9.9%，孔铜25 µm仍是假定。实际钳位上界、MOS开关损耗、回生脉冲和散热必须测试；RH050标称50 W不能直接当作机器人内可连续耗散50 W。

## 结构、模型与质量

Blender含三个场景：完整装配、入口板安装细节、合板/卧装电容/托架细节。733项表示468项原R20保留几何加265项新装态几何/包络，不是733个采购或制造件；另有9项拔插服务包络。各物体可以单独选取、隐藏，并查看原文件及所属关节。短线束预算不代表整机完整布线，保守器件包络不用于按体积计算器件重量。

入口板保留原底脚位置，改四孔框架与5 mm PEEK隔柱；背面元件2.7 mm高，对框架有名义2.3 mm余隙。四个M2工具通道用1.5 mm内六角L形扳手的Ø2×30 mm工作段核验。电容托架使用原H1/H2、不增加PCB孔，正X泄压端开放。套管上端已从z8.1改至7.9 mm；[精确STEP子集及间隙证据](mechanics/insulation_v2/subset_proof.json)确认两处原参考模型微交叠消除，套管到弯脚工程包络的最小名义距离约0.025 mm。这处很小的名义间隙仍需实物成形/绝缘验收。

安装、静态接触及按R21原轨迹关节范围的几何增量证据见 `mechanics/motion_delta/` 的最终报告。该检查可评价新几何在既定关节范围内的分离，不产生新的动力学仿真或质量/重心结论。

[有限质量与重心审查](integration/mass_review/质量与重心影响_有限范围审查.md)显示：增加内层铜后，五块新旧裸板材模型的铜名义增加约2.741 g；裸材减少约0.937 g，加本次附件毛差后名义约+0.04 g，误差足以改变符号。器件、焊料、换插头及完整线束未称量，不能给出精确新整机质量或COM，也不能继承R21动态平衡、扭矩或行走放行。

## 仍需闭合的实际工程项目

1. 合板到机身的主支架、完整电阻/电源线束、热连接与装入顺序。电容托架只固定电容到PCB，不能视为完成PCB到机身的主支承。
2. 加工厂叠层、孔铜、填孔盖铜、局部细间距及装配工艺；卧装电容成形和绝缘、绑带拉脱与热蠕变、M2叠层拧紧试样。
3. 5V全负载/低输入/纹波/切换、电源温升、回生瞬态与功率电阻温度；最终质量替换后重新核对重心和运动，再进行实体受载与行走验收。

本次不改变RK3576软件接口、保护阈值或历史训练权重。来源与分别适用的许可沿用[仓库NOTICE](https://github.com/ldcyes/OpenDuck/blob/main/NOTICE.md)；历史原生设计和交付包未覆盖。

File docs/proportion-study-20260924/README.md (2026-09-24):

# 腿部比例与电机筛选：2026-09-24

后续：用户已采用A，实施与验证见[R26覆盖件](../../hardware/r26-cover-first/README.md)。下文保留为改动前的方案分析。

[English](README_EN.md) · [返回首页](../../README.md)

**状态：设计比较，尚未修改制造结构、执行器BOM或批准步态。610 mm不是设计目标。** 用户已要求改善腿部比例，并允许必要时增加高度；应先消除遮挡，再判断实际腿长和电机尺寸，不把整机等比例放大作为默认办法。已选择的鸭头左侧孔永久闭合方案继续有效，但不在本次只读测量中假装完成。

## 当前模型的实测结果

测量源是R25完整Blender装配，核验其SHA256后，按逐件实际顶点和装配矩阵计算包络。排除默认隐藏的服务参考。另将R21准备站姿应用到R25几何，只用于比较尺寸；这不是R25步态或稳定性验证。

| 项目 | 结果 |
|---|---:|
| 装配中可见几何项 | 1,151 |
| HOME装配姿态全高 | 570.393 mm |
| 套用R21准备站姿后的全高 | 577.830 mm |
| 左大腿：髋俯仰至膝轴的三维距离 | 88.599 mm |
| 左小腿：膝至踝轴的三维距离 | 103.732 mm |
| 两段轴间距之和 | 192.331 mm |
| HOME髋至踝的垂直距离 | 157.400 mm |
| 左大腿覆盖件侧面X/Z包络 | 108.638 × 116.969 mm |
| 覆盖件下缘低于膝轴 | 27.224 mm |
| R25工程质量估计 | 4.447479 kg |
| R21四工况动力学模型质量 | 4.195094 kg |

轴间距包含横向偏置和屈膝方向，不能直接解释为腿的可见高度。侧面覆盖件下缘超过膝轴27.2 mm，与“腿短”的视觉感受有关，但这个投影测量不是可见像素遮挡面积，也不是碰撞间隙。

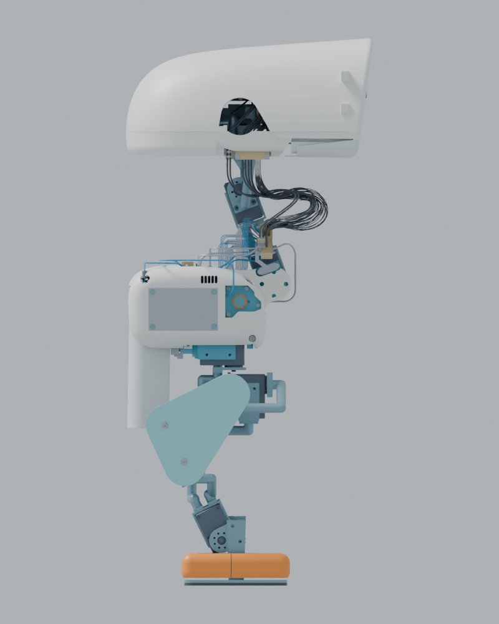
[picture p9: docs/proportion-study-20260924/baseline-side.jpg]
当前R25正交侧视，未修改几何


[正交正视](baseline-front.jpg)。两张图保持原装配HOME姿态，不使用倾斜相机来判断比例。

## 三种方案

| 方案 | 轴间距合计 | HOME高度估计 | 相同准备关节角下高度估计 | 取舍 |
|---|---:|---:|---:|---|
| A，优先重画覆盖件 | 192.33 mm | 570.39 mm | 577.83 mm | 优先建议；不增加腿部力臂，但实际腿长不变 |
| B，腿段矢状面分量加10% | 209.23 mm | 586.13 mm | 594.30 mm | 腿部确实变长，需要新连杆、安装件、线束与步态 |
| C，腿段矢状面分量加15% | 217.74 mm | 594.00 mm | 602.53 mm | 外观变化更明显，载荷与结构重做范围更大 |

B/C只放大髋—膝及膝—踝向量的X、Z分量，保持各轴HOME横向位置，避免连髋宽一起放大。由于Y分量保留，三维轴间距的增幅不等于10%或15%。表中高度是同关节角、同脚部偏置下的运动学估计；包含新支架、电机、脚底接触和最终站姿后的高度仍须重新确定。脚部横向落点也可能随关节旋转改变，不能沿用旧接触多边形。

A方案的具体设计目标：将覆盖件下缘由膝轴下27.2 mm收至约10 mm，理论上收回17.2 mm的垂直遮挡；保留原曲面语言，重新设计圆滑下缘。覆盖件侧向内收先以4 mm作为检查候选，重做对应支座，不能仅平移装配件。必须核对两颗外壳螺钉、垫圈、螺母、孔边距、工具通道和膝关节连续扫掠后再确定实际轮廓。当前包络测得壳内侧与髋俯仰电机最外点的Y向差约11.27 mm，只是筛选参考，不能作为全程净空。

## 电机筛选

R25实际清单为12个XM430、3个XC330；腿部10个关节均为XM430。所有商品电机必须使用厂家真实尺寸与接口，不能把电机网格按外观缩小。

| 型号 | 厂家尺寸W×H×D | 质量 | 11.1 V堵转扭矩 | 本次判断 |
|---|---|---:|---:|---|
| XM430-W350-T | 28.5×46.5×34 mm | 82 g | 3.8 N·m | 现有承重关节比较基线；持续能力尚未实测 |
| XM335-T323-T | 19×35×22 mm | 27 g | 1.03 N·m | 更小候选；优先研究头俯仰及髋偏航，不能直接替换髋俯仰、膝、踝 |
| XC330-T181-T | 20×34×26 mm | 23 g | 0.76 N·m | 保留头偏航、头滚转、嘴部候选用途，不升级为腿部承重电机 |
| XM540-W270-T | 33.5×58.5×44 mm | 165 g | 10.0 N·m | 更大、更重；四个髋俯仰/膝电机替换至少增加332 g，不含新支架，不作为改善腿部纤细比例的首选 |

规格核对日期2026-09-24；来源：[XM430](https://emanual.robotis.com/docs/en/dxl/x/xm430-w350/)、[XM335](https://emanual.robotis.com/docs/en/dxl/x/xm335-t323/)、[XC330](https://emanual.robotis.com/docs/en/dxl/x/xc330-t181/)、[XM540](https://emanual.robotis.com/docs/en/dxl/x/xm540-w270/)。表中是堵转值，不能作为低电量持续扭矩。XM335和XC330的最高输入电压为12.0 V，也不能未经电源范围核查便接入XM430允许的14.8 V总线。

对现有R21四种工况取每关节的最大绝对峰值及最大RMS，再取左右腿较大值：

| 关节组 | 历史峰值N·m | 历史RMS N·m | 当前判断 |
|---|---:|---:|---|
| 髋偏航 | 0.410 | 0.182 | XM335可研究，尚不能按堵转值定型 |
| 髋侧倾 | 0.825 | 0.493 | 不直接缩小 |
| 髋俯仰 | 1.175 | 0.527 | 不直接缩小 |
| 膝 | 1.043 | 0.690 | 不直接缩小 |
| 踝 | 0.807 | 0.459 | 不直接缩小 |
| 颈俯仰 | 0.499 | 0.402 | 长时间负载较高，暂保留XM430 |
| 头俯仰 | 0.210 | 0.108 | 可优先研究小电机，但新头盖、相机和线束负载必须重算 |

这些负载来自4.195 kg的旧模型，不能直接证明4.447 kg的R25适用。每个XM430换成XM335的电机本体减重55 g；仅头俯仰为55 g，连同两个髋偏航则为165 g，但均未计安装支架差额，也没有完成持续扭矩、电压、回差或径向载荷验证。

## 为什么现在不直接拉长或换大电机

R25比R21动力学模型的质量高6.02%。作为一阶敏感性筛选，将旧峰值乘以质量比，再乘矢状面长度系数；如要求15%容量余量，则以该筛选峰值除以0.85。原长度下髋俯仰约需1.465 N·m，B方案约1.612 N·m，C方案约1.685 N·m。旧模型对该关节使用的1.35 N·m本身也只是未实测的能力假设。

这不是新结构的逆动力学结果或保守上界；质量分布、接触力分配、角加速度和新电机惯量会改变实际需求。因此筛选只能指出“不能按旧结论直接放行”，不能证明任何候选已经足够或必然不足。

## 下一阶段设计与验收输入

1. 先评审A的覆盖件轮廓；若仍需实际加长，优先B，C保留为对照。610 mm不作为约束或承诺。
2. 选定方案后，同步更新真实电机/支架、连杆、固定五金和完整线束，不只修改显示网格。
3. 按最终装配更新质量、重心和惯量；对准备、单脚支撑、摆腿、转向和停止动作求解接触与动态负载，输出峰值、RMS、持续时间及转速。
4. 对低电量端电压、最不利环境温度与目标1–2小时工作周期制定持续/周期负载台架验收；保留15%容量余量定义。持续能力必须由厂家适用曲线或实测支撑。
5. 连续碰撞检查覆盖腿部外壳、连杆、电机、所有五金、脚部和线束，并检查公差和装配工具通道。独立检查曲面闭合、壁厚、打印导出、装配坐标与接口。
6. 头部B方案仍需完成曲面闭合及新增干涉复核。旧下壳/嘴部约8.75°起的冲突继续列为未闭合项，不能因去掉侧孔而隐藏。

本次完成的是测量与方案筛选，尚无新腿部STL/STEP、装配Blender、电机最终采购定型或实物测试结论。

## 证据与复算

- [逐件测量与源文件哈希](baseline_measurements.json)
- [三方案坐标、四工况负载与敏感性结果](candidate_screen.json)
- [测量源程序](measure_baseline.py)、[筛选源程序](compare_candidates.py)

源程序需放回完整工程根目录的`work/r26-proportion-study/`运行，依赖R25完整装配、R21准备站姿/四工况报告及R11运动学源；此Git仓库不是全部依赖的副本。运行入口：`work/tools/blender/blender --background --factory-startup --python work/r26-proportion-study/measure_baseline.py`，然后`python3 work/r26-proportion-study/compare_candidates.py`。输入的原始工程路径及SHA256记录在JSON内。图和输出为几何/数值设计资料，不是实物照片。

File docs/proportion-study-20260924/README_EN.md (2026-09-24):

# Leg proportions and actuator screening — September 24, 2026

Follow-up: option A is now implemented in [R26](../../hardware/r26-cover-first/README_EN.md). The study below remains the pre-change comparison.

[中文完整分析](README.md) · [English project overview](../../README_EN.md)

**Design study only. No manufacturing geometry, actuator BOM or qualified gait has been replaced. A height of 610 mm is not a design requirement.** The previously selected permanent closure of the left head opening remains pending implementation and validation.

The source-checked R25 Blender assembly measures **570.393 mm** tall in its saved HOME pose. Applying the earlier R21 preparation joint angles gives **577.830 mm**; that is a kinematic comparison, not a new R25 balance or collision result. The hip–knee and knee–ankle axis distances are **88.599 mm** and **103.732 mm**. Their sum, **192.331 mm**, includes lateral offsets; vertical hip-to-ankle separation in HOME is only **157.400 mm**.

The thigh cover extends **27.224 mm below the knee axis**. Redrawing its lower edge to about 10 mm below that axis could expose approximately 17.2 mm more of the knee/lower-leg region without increasing joint moment arms. This is an envelope observation, not a pixel-occlusion or clearance measurement. Fasteners, edge distances, access, mounts and continuous knee motion must be checked before changing the printable part.

Existing R25 assembly, orthographic side view

[Orthographic front view](baseline-front.jpg). Both images retain the original HOME geometry.

| Alternative | Combined 3D leg-axis lengths | HOME height estimate | Same preparation-angle height estimate |
|---|---:|---:|---:|
| A — redraw covers first, recommended | 192.33 mm | 570.39 mm | 577.83 mm |
| B — extend sagittal leg-vector components by 10% | 209.23 mm | 586.13 mm | 594.30 mm |
| C — extend sagittal leg-vector components by 15% | 217.74 mm | 594.00 mm | 602.53 mm |

B/C preserve HOME lateral axis positions rather than scaling hip width. Because lateral components remain unchanged, their combined 3D lengths do not increase by exactly 10%/15%. These height estimates retain joint angles and existing motor/foot offsets. New CAD, mass, foot contacts and the final stance can change them. A real redesign must re-solve both feet and contact forces.

The actual R25 inventory has twelve XM430 actuators and three XC330 actuators, with XM430 at all ten leg joints. Commercial motor models must retain manufacturer dimensions; visually scaling a motor is not a valid substitution.

| Actuator | W × H × D | Mass | Stall torque at 11.1 V | Screening result |
|---|---|---:|---:|---|
| XM430-W350-T | 28.5 × 46.5 × 34 mm | 82 g | 3.8 N·m | Existing loaded-joint baseline; sustained capacity remains unmeasured |
| XM335-T323-T | 19 × 35 × 22 mm | 27 g | 1.03 N·m | Smaller candidate for head pitch and possibly hip yaw; not a direct substitution at loaded pitch/knee/ankle joints |
| XC330-T181-T | 20 × 34 × 26 mm | 23 g | 0.76 N·m | Retain candidate head yaw/roll and mouth uses |
| XM540-W270-T | 33.5 × 58.5 × 44 mm | 165 g | 10.0 N·m | Larger and heavier; four hip-pitch/knee replacements add 332 g before new mounts |

Manufacturer specifications checked September 24, 2026: [XM430](https://emanual.robotis.com/docs/en/dxl/x/xm430-w350/), [XM335](https://emanual.robotis.com/docs/en/dxl/x/xm335-t323/), [XC330](https://emanual.robotis.com/docs/en/dxl/x/xc330-t181/), [XM540](https://emanual.robotis.com/docs/en/dxl/x/xm540-w270/). Stall torque does not establish sustained output. XM335/XC330 allow at most 12.0 V input, so they cannot automatically share an XM430 supply that can reach 14.8 V.

Across the earlier four R21 cases, the larger left/right hip-pitch peak is 1.175 N·m and knee RMS is 0.690 N·m. Neck-pitch RMS reaches 0.402 N·m; head pitch is lower at 0.108 N·m. These observations prioritize head pitch for smaller-actuator investigation, but the updated camera, shell and harness loads must be included. One XM430-to-XM335 substitution saves 55 g in motor mass; three save 165 g, before mount changes. None is an approved substitution.

R25's estimated **4.447479 kg** is **6.02%** above the **4.195094 kg** R21 dynamics model. A first-order mass-and-arm sensitivity calculation gives hip-pitch capacity requirements of approximately 1.465, 1.612 and 1.685 N·m for A/B/C if 15% capacity reserve is requested. This calculation is **neither inverse dynamics nor a conservative bound**. It cannot replace a new model with actual COM/inertia, contact allocation, accelerations and actuator limits. The former 1.35 N·m model limit was itself unqualified.

The next design stage should first redraw the covers, then use B if actual leg extension is still needed. It must update mounts, hardware, harnesses, mass/COM/inertia, collisions and gait together. Low-battery cyclic/sustained torque and temperature over the intended 1–2 hour duty period need applicable manufacturer data or bench measurements. No new STL/STEP, integrated Blender assembly, final actuator purchase selection or physical acceptance is claimed here.

Evidence: [per-part dimensions and input hashes](baseline_measurements.json), [candidate coordinates and sensitivity results](candidate_screen.json), [geometry measurement source](measure_baseline.py), and [screening source](compare_candidates.py). Scripts run from `work/r26-proportion-study/` within the full original engineering workspace and need the R25 assembly, R21 records and R11 kinematics; this Git repository alone does not contain every dependency. The [Chinese analysis](README.md) specifies the reproduction commands and remaining checks, including the existing mouth/lower-shell conflict.

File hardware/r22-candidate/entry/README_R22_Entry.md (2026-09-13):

# Entry 5V R22：可编辑设计审查候选

现板 52 × 42 × 1.60 mm，四层，面积 2184 mm²；权威 R13 继承源为 65 × 45 mm，面积下降 25.33%。本目录包含实际已布线、重铺铜的原生工程，不是占位外形。未制造、未下单、未做温升/负载/EMI 实测；2.7 A 设计工作预算和 3 A 上限仍须实际供电与热验证。

## 打开与审查

- 编辑入口：`Microduck_Entry_5V_R22.kicad_pro`；同名 SCH、PCB、DRU 和本地 `footprints/`、符号库、库表一起保留。
- 板图：`preview/Entry_R22_PCB.pdf`（四铜层和正反装配层），`Entry_R22_Top.svg/.png`、`Entry_R22_Bottom.svg/.png`；原理图 PDF/SVG 同目录。
- 58 件 BOM、物理针脚网名：`assembly/`；完整机械接口：`Board_Interface_R22_Entry.json`。
- 主验收记录：`verification/electrical_equivalence.json`、`ERC.json`、`DRC_original_rules.json`、`DRC_all_rules_enabled.json`、`DRC_fabrication_rules.json`。
- 电源压降以 `verification/DC_New_vs_Source_Final.json` 为准；中心线简化筛查仅作路径诊断。热场景和原生铜面积在 `power_copper_thermal_audit.json`。
- `DELIVERABLE_SHA256.json` 列最终审查文件摘要。`verification` 其余带 candidate、seed、routing、before、post 等名称的中间记录仅为诊断历史，不是放行结果。

## 电路等价与明确变更

源为 `work/r13-electronics/inherited/Entry_5V_R8/` 现行 SCH/PCB，未覆盖。58 个位号、200 个数字铜焊盘实例、159 个原理图物理针脚逐项比对等价；全部值和全部 IC 型号保留。8 个逻辑/传感插头、8 个电源焊线端、四端 WSL27262L000FEA 2 mΩ 分流器、0448002.MR 2 A 保险、保护与阈值不变。

为解决实机颈轨及头壳的出线、弯线和拔插空间，已授权将 J3/J5/J6/J7/J8 改为同族真正顶插 BM02/BM08/BM03/BM03/BM05B-SRSS-TB(LF)(SN)。J1/J2/J4 继续侧插 SM02/SM02/SM10。新 BM 焊盘、固定脚、Fab、方向、料号均在 SCH/PCB/BOM/接口中显式替换；仍用对应 SHR 壳和 SSH 端子，逐针网名完全相同。[JST SH 原厂图](https://www.jst-mfg.com/product/pdf/eng/eSH.pdf)

U1/U2 使用 TI DGS0010A 原厂推荐的 1.45 × 0.30 mm 焊盘、0.50 mm 节距、4.40 mm 行中心距，取代通用库的 0.35 mm 宽盘。器件本体、机械包络、料号和针号保持；本地封装名为 `TI_DGS0010A_Manufacturer_1p45x0p30`。原厂尺寸截图见 verification。[INA226](https://www.ti.com/lit/ds/symlink/ina226.pdf)、[ADS1115](https://www.ti.com/lit/ds/symlink/ads1115.pdf)

## 制造与机械接口

名义对称叠层为 F.Cu 0.070 / PP 0.185 / In1.Cu 0.035 / Core 1.000 / In2.Cu 0.035 / PP 0.185 / B.Cu 0.070 mm，两面阻焊各 0.010 mm，总计 1.600 mm。此为工程叠层提案；成品厚度、公差、2 oz 最小成品铜厚、25 µm 孔铜及填孔盖铜工艺需厂家按实际报价确认。In1 为 GND 参考层，未布置信号走线；In2 承担信号与局部电源铜。

保留原项目尺寸规则并仅加严 DRU：全局铜距 ≥0.16 mm、新线宽 ≥0.20 mm、Zone 铜距 ≥0.205 mm。严格全局 0.20 mm 的附加诊断只剩四处 0.175 mm 的局部过孔—逃线间距，见 `DRC_nominal_0p20.json`，没有 Zone 间距违规。分别为 I2C_SDA 过孔 (45.3,7.5)、两个 LOGIC_VIN 过孔 (10.6,23.7)/(10.6,24.7)、GND 过孔 (17.3,15.5)。这些必须作为真实 2 oz 制造约束告知厂家，未降低规则隐藏。0.175 mm 高于厂家公布的 0.16 mm 下限。[JLCPCB 铜厚能力](https://jlcpcb.com/help/article/jlcpcb-copper-weight)

四个 Ø2.2 mm 安装孔中心为 (3,3)、(23,3)、(3,39)、(49,39) mm。机械父装配姿态保持 R=[[1,0,0],[0,0,-1],[0,1,0]]，t=[−3,−8,259]，jaw_soft；孔位/器件姿态均以 JSON 为准。正面真实最大高 13.0 mm（C11），C18 最大 12.7 mm；背面 C14/C15 最大 2.7 mm。5 mm PEEK 柱名义留下 2.3 mm 背件至铝架距离，柱、螺钉、垫圈和工具空间由整机机械审查另核。

BM 配对总高原厂约 6.3 mm，采用 6.5 mm 预算，保留 +Z 方向 5 mm 直出、R5 弯线和 8 mm 拔插空间。J5 最终中心 (33.4,4.0)；其余接口均已冻结。8 个焊线端使用 Ø6 mm 铜盘、Ø2.4 mm 孔，正反各 7×7 mm 工艺 courtyard；不能将焊线和焊锡过程包络当作零厚度点。正面已加 W1–W8 与正负极丝印。

## 电源铜、压降与热边界

重铺后 U3 PGND14/15/18 位于同一块顶层连续地铜；AGND 独立，SW 只在模块引脚间局部连接，无 SW 过孔或外引铜区。保留四层地铜，未删地以获取 DRC 通过。模块 PGND 和 VOUT 各 10 个 Ø0.45/0.20 mm 热/电流孔，MUX 四组各 4 个并联孔；涉及盘内孔要求填孔盖铜。铜面积不是有效散热面积。[LMZM33603 布局/热要求](https://www.ti.com/lit/ds/symlink/lmzm33603.pdf)

实际原生铺铜、焊盘、走线和贯穿孔提取后，用同一铜电阻率、温度系数和 25 µm 孔铜假设对比。过孔沿周向 32 扇区分布连接各铜层；源/目标盘为理想等势端子，焊点/触点/线束另计。电源路径采用 0.05/0.025 mm 网格，地回流采用 0.10/0.075 mm；新板细网格变化不超过 2.5%，地回流不超过 0.6%。四个解析基准（均匀铜片和单孔/四孔）通过，但这不构成实际电热验证。

| 完整板内回路（含地） | 源 R20 | R22 R20 | 改善 |
|---|---:|---:|---:|
| MOBILE：U3 → MUX 输入、MUX 输出 → W7、W8 → PGND | 21.290 mΩ | 10.502 mΩ | −50.67% |
| BENCH：W5 → MUX 输入、MUX 输出 → W7、W8 → W6 | 13.084 mΩ | 6.933 mΩ | −47.01% |

其中 MUX 本身另按 33 mΩ 最大值（−40…105°C，5 V/3.3 V 表项）计入，绝不采用典型 18.5 mΩ。LMZM VFB 全温最低 0.98 V、41.0k/10.0k 电阻各初始 ±0.1% 得分压下限 4.98997 V；再计两个电阻独立 ±25 ppm/K、80 K 温差后为 4.97396 V。[TPS2117](https://www.ti.com/lit/ds/symlink/tps2117.pdf)、[Yageo 电阻规格](https://www.yageogroup.com/component-documentation/download/specsheet/RT0603BRD0710KL)

以铜温 105°C、有效铜截面只有名义 80%、另加 5% 数值模型余量作工程筛查，2.7 A 的板端电压约 4.835 V，3 A 约 4.820 V，尚未扣纹波、动态额外下陷及外部线束/触点。TI 的 10 mVpp 纹波和 0.04% 负载调整率均仅为典型，没有可据此保证的最大值。若实测满足纹波 ≤50 mVpp、额外动态下陷 ≤20 mV，2.7 A 外部总回路电阻仍须低于约 14.9 mΩ；3 A 约 8.3 mΩ。该条件是验收预算，不是已验证能力。

BENCH 5 V±5% 电源若落到 4.75 V，经过任何正压降后都不能保证负载 4.75 V；源板同样存在此边界。2.7 A 时仅板铜与 MUX 就要求 W5/W6 输入约 ≥4.872 V，纹波/动态/线束还需另加，详 JSON。

LMZM 3 A 是器件额定上限，四层本身不能证明封闭头壳可持续输出 3 A。热报告列效率 85/90/93%、有效热阻 25/35/45 K/W 与 50°C 环境的场景；原厂 63×63 mm 四层 2 oz 的 18.9 K/W 不直接套用。须实测最低电池电压、2.7 A 工作及 3 A 峰值的 W7/W8 电压、纹波、温升、保护及切换；2 A 输入保险还要核启动浪涌与温度降额。主 3.8 mm 电池通道和 2 mΩ 分流器的损耗不能由上游 15 A 保险标称推定持续载流通过。

## 可重复工具链

KiCad 10.0.6，`work/tooling/kicad-python` 与 `work/tooling/kicad-cli`。在原 workspace 中，最终 PCB 可由 `build_entry.py` → `apply_routes.py`（读取已审查 routes.json）→ `finalize_labels.py` 重建，随后重铺铜/DRC/接口/网表等价导出。`prepare_routes.py`/`route_entry.py` 是探索布局的路由工具；重跑路由会生成新候选，必须重新审查。`augment_power.py`、`finalize_routes.py` 等为废弃诊断尝试，不属于最终重建顺序。

DC 求解脚本 `solve_dc_copper.py` 提供 `solve(d, net, src_pins, dst_pins, grid_mm)`，只读 native 几何 JSON。使用系统 Python 的 numpy/scipy 和 shapely2，建议 OPENBLAS_NUM_THREADS=1、OMP_NUM_THREADS=1。`.deps` 是本地运行缓存，不是设计交付依赖。源文件 SHA 和最终文件 SHA 已记录；没有修改任何原源文件。

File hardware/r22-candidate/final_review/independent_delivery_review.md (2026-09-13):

# R22 最终交付独立审查

审查范围是本次 Entry 5V 与 Power/Regen 紧凑候选、它们的冻结证据和 R22 装配交付口径。没有修改原生设计、机械件或历史源，没有重复大型 DC 求解。两项发现均已关闭；最终运动总索引、当前 Blender 与暂存映射核对通过，未发现阻断本次工程候选资料交付的错误。本记录不授予加工、持续电流、热、回生或实体行走验收。

## 已关闭的发现

| 发现 | 核查与处置 | 证据 |
|---|---|---|
| 原始 freeze 摘要的“全部规则”只包括 DRC，ERC 仍保留四个默认忽略类别 | 在精确副本把 single_global_label、four_way_junction、simulation_model_issue、footprint_filter 全部提升到 warning，并使用全部严重级别。两板均返回 0、违规 0、ignored_checks=[]。没有更改冻结 SCH/PCB。 | `frozen_input_audit.json`、`supplemental_erc/entry/ERC_ALL_CHECKS.json`、`supplemental_erc/power_regen/ERC_ALL_CHECKS.json` |
| 自动 Gerber 作业元数据与有效规则不一致：Entry 沿用 0.15 mm 默认值；尺寸包含 0.05 mm 轮廓笔宽；Power 还有无目标的受控阻抗标记 | 根任务把两个自动 gbrjob 从加工文件集合移出，以原 SHA 保存为明确标记的诊断 JSON，说明名义尺寸按 Edge.Cuts 中心线、工艺按 DRU 与报告。审查者独立从冻结 PCB 新导出 26 个 Gerber/钻孔文件，除时间注释外与最终加工文件逐字相同。 | `fabrication_export_audit.json`、`../fabrication/automatic_job_disposition.json` |

## 冻结内容核对

- Entry 使用 `final_verification/freeze_v1/entry`，PCB SHA256 `4bc1e078a2154a1cc74f0e4f09b0d707fa98e8a63f1475ab6f4e5a411cb70c95`；Power 使用 `freeze_v2/power_regen`，SHA256 `ef5de594e8bd6cd100a9dcf30c199a215c0227087a3f633df344f4f3dfbe78a4`。Power 的 freeze_v1 属于旧过程，不替代最终版本。
- 冻结副本与作者目录的原生、根/子原理图和本地库逐文件一致；ERC/DRC 报告本体 SHA 与摘要一致，全部 DRC 类别启用后的违规、未连线、原理图对应均为 0。补充 ERC 已覆盖默认忽略类别和全部严重级别。
- 独立规范化排序后，机械参考与最终原生的全部元件坐标、方向、焊盘、孔径、Fab 和轮廓几何相同：Entry 58 个封装，Power 84 个。Entry 参考 PCB 旧摘要仅反映已证明不改变这些机械几何的电气/丝印更新。
- 逐项读取严格 0.20 mm 诊断：Entry 4 对、Power 15 对均实际为 0.175 mm，全部是局部逃线/过孔/焊盘组合，Zone 项为 0。没有把有效规则通过写成全板任意间距都大于等于 0.20 mm。
- Entry 91 项交付清单、Power 当前交付清单与两块权威旧 Power/Regen 源的 110 个文件摘要均匹配。针网等价记录、明确 BM 插头替换、INA226 地址与独立辅助网、保护/默认关闭说明互相一致。没有根据同名内部网盲合并，也没有把完整 TDK 模块缩小。

具体自动核对结果见 `frozen_input_audit.json`、`delivery_binding_audit.json`。总 README 已正确说明实际面积 6694/7785 mm²，减少 14.01%，并区分阶梯面积与外接矩形。

## 模型与质量口径

当前 selection 的 733 项确为 468 项原 R20 完全保留行加 265 项新几何/包络；删除的 89 项与新增作用域一致。另 9 项拔插包络单列。所有引用的 STEP/STL 摘要匹配，不能把这个数量改称制造 BOM 件数。Blender 及三张预览图与 278 个读取源摘要一致，733 项读回记录已绑定当前 selection；本审查没有重跑渲染。

质量报告的 5 个新旧裸板算式、材料来源及摘要一致。Entry 裸材名义减少 1.949 g，Power 合板裸材反增 1.012 g，合计裸材约减少 0.937 g；加已列附件毛差约 +0.04 g。该模型未称量器件、焊料、换插头及完整线束，不能据面积缩小或四层结构宣布净减重、新整机 COM、续航或动态平衡通过。总 README 对此已有明确限制。

总 README 也保留了合板到机身主支架、完整线束和热连接尚未闭合的事实；电容托架不是整块 PCB 到机身的主支承。0.025 mm 套管到成形脚名义间隙属于工程包络结果，必须保留成形与绝缘实物验收边界。

## 最终交付绑定

最终 `motion_delta/latest_summary.json` 与 `latest_verification.json` 的源文件摘要、有效 733 项逐件几何/姿态/关节归属均匹配当前 selection。93,595 对具有相对运动的配对在 R21 已记录 195.44175 s 的关节包络内均满足 2.2 mm 目标，最低证书下界 2.230402829 mm。它不是测得的真实最小间隙，也不是重新模拟 R22 的动力学。

65,405 对静态配对分为 65,088 对正间隙、256 对名义零体积贴合、61 对具名螺纹/同体表示，算术分区完整，当前未解释有限交集为 0。动态 2.2 mm 目标不能扩展到这些固定装配面、0.025 mm 套管名义间隙或 73 对针线包络的 0.140089 mm 名义下界。托架的最终 1,980 对组合复核和套管 v2 子集继承已有明确补充入口，旧 113 件参考和旧套管冲突记录被保留为历史证据。

独立核对最终总索引来源、174 个受保护旧文件、运动验证的 1,264 个来源项和 Blender/预览来源；均匹配。暂存映射快照含 1,880 个文件、343 个 Git 目标：每个源文件和副本的字节数及 SHA 相同，目标路径唯一，实际暂存集合无遗漏或过期额外文件。两板根/子原理图、PRO/PCB/DRU、本地库及最终几何入口都在包内，误导性的自动 gbrjob 不在加工集合。

本次最后 16 项绑定检查见 `final_handoff_audit.json`，完整结果见 `final_review.json`。上述暂存计数和摘要绑定于检查时快照；根任务将把本最终审查报告追加后再次准备资料包，并负责 ZIP CRC/SHA 与远程发布资产核验，本审查没有提前宣称这些动作已完成。

原生规则验证、数值 DC、装配几何与实体性能验证相互独立。主支承、工艺、负载/热/回生以及实体运动的开放项仍按总 README 保留。本次可交付的是明确标注的工程候选资料。

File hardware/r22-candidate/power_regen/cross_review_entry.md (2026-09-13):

# Entry R22 只读交叉审查

范围仅限本轮 Entry 最终电源铜路、AGND/PGND、SW/热孔和 MUX 压降；不扩大到其他板。已按 Entry 最终冻结版本复核，未发现阻止交付工程候选的电气布局差异；物理性能仍未验收。

已直接读取原生 PCB（读取记录见 `cross_review_entry_native.json`），核对 LMZM33603 / TPS2117 实际编号焊盘和走线。AGND_5V 保持独立，仅回接低噪声设定支路，未并入系统 GND 铜区；该芯片 AGND 与 PGND 内部连接，外板不另短接的处理符合 [TI LMZM33603 数据表](https://www.ti.com/mx/lit/gpn/lmzm33603)。SW_INTERNAL 仅两段位于封装边缘的等电位连接，无 SW 过孔、无外延 SW 铜区；避免把高 dv/dt 开关网作为热扩展铜。PGND18 的 10 个热孔和 VOUT 的10个热孔各自归网，没有用SW孔替代。PGND14/15/18 在原生正面同一个 GND 铜多边形上，仍须靠成品孔铜、填孔、焊点/空洞及温升实测确认散热性能。

TPS2117 针网符合 [TI 原厂表](https://www.ti.com/lit/ds/symlink/tps2117.pdf)：3/6为双输入、2/7为并联输出，5脚模式端随BENCH_5V设置源优先功能。预算用5V、−40..105°C最大33mΩ，而非18.5/20mΩ典型值，方向正确。2.7A/3A档位也必须减去实际双程铜、电源线、接点和下游负载开关的压降，不因“4A MUX”标签宣称整机4A或3A电压合格。裸MUX在3A、33mΩ约0.297W，不包含其他发热。

最终冻结 PCB SHA256：`4bc1e078a2154a1cc74f0e4f09b0d707fa98e8a63f1475ab6f4e5a411cb70c95`；DC几何SHA：`876aa0a81a186797ca0b253b5fe61861636d1f1ca0ba8b3e93f4a89ea84daf59`。本审查重新从源与最终原生板独立导出并逐项比较全部参与求解的铜多边形、焊盘、轨迹、过孔，均与 Entry 求解输入一致。新板167个多边形、96个焊盘记录、543段轨迹、148个含THT的孔记录；对照见 `cross_review_entry_dc_equivalence.json`。这确认求解使用完整最新铜区，非早期遗漏轮廓版本。

| 实际路径 | 源 R20 / mΩ | R22 R20 / mΩ |
|---|---:|---:|
| F1→LMZM VIN | 8.433 | 7.114 |
| LMZM VOUT→MUX | 12.491 | 7.792 |
| BENCH→MUX | 4.665 | 4.387 |
| MUX→W7 | 8.367 | 2.424 |
| MOBILE 完整板内双程 | 21.290 | 10.502 |
| BENCH 完整板内双程 | 13.084 | 6.933 |

0.05/0.025mm功率路径网格变化在R22为0.46..2.49%，0.10/0.075mm地回流变化0.17..0.33%；数值求解收敛不代表制造公差或温升认证。BENCH局部地路径由0.0522增至0.1220mΩ，但其完整板内环路仍约下降47%；不能声称每个局部路径都减阻。两种工作模式的完整板内环路均降低，前期中间版本的BENCH疑点已关闭。

最终预算进一步计入分压电阻独立温漂，静态设定下限由初始4.99V收紧为4.974V；正确保留“负载调整率/纹波只有典型值，不能保证所有负载瞬间最低输出”的限制。以105°C铜、80%截面、5%数值余量、MUX33mΩ的条件场景，2.7A在W7/W8约4.835V、3A约4.820V，尚未扣线束/纹波/额外动态跌落。若另行验证纹波50mVpp、动态额外20mV预算，外部双程电阻分别需约≤14.9mΩ/8.27mΩ。BENCH端则应按最终文件给出的最低W5/W6输入和实际线束余量接受，不能固定写“接5V即合格”。详见 Entry `verification/DC_New_vs_Source_Final.json`。

尚未做任何样机负载、温升、最低电池电压、MUX切换波形或线束接点测量；此审查不能替代这些物理接受项目。

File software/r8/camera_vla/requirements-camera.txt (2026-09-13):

# RK: system python3-opencv with GStreamer enabled; the pip wheel may lack it.
# Protocol/HTTP/dry tests need only Python3.10+ standard library.

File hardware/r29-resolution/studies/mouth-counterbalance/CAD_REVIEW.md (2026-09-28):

# R29 嘴轴被动平衡：线圈空间可行性研究（未装入 R29）

本目录是可选设计研究，不修改已冻结的 R29 装配、Blender 或行走模型。当前嘴轴在四条无弹簧数值轨迹中峰值约 0.05925 N·m，超过现有 0.05 N·m 结构限制；因此无弹簧 R29 **不能按该限制宣称嘴部行走验收通过**。

## 弹簧设计假设

拟在嘴轴两只并列的定制钢丝扭转弹簧，每只线径 0.7 mm、平均圈径 11.5 mm、3 有效圈。弹簧使开嘴过程继续收紧，并对嘴部施加闭合方向力矩。钢丝弹性模量暂按 200 GPa，闭嘴位置每只预载 0.010 N·m；材料牌号、热处理、制造公差与供应商额定值均未锁定。

[Gutekunst Federn 厂家设计手册](https://www.federnshop.com/download/pdf/Gutekunst-Federn-1x1-2013-E.pdf) 第 20–21 页 1.4.4 节给出螺旋扭转弹簧的力矩/角度、弯曲应力、线圈体长和受载内径收缩公式，并要求导向芯轴、沿收紧方向加载，避免腿部锐角。按该手册公式，双弹簧总刚度约 **0.043496 N·m/rad**，闭嘴预载 **0.0200 N·m**，开至 10° 时总闭合力矩约 **0.027592 N·m**。每只弹簧的修正弯曲应力估算从 **312.5 MPa** 增至 **431.1 MPa**；受载内径估算最小 **10.426 mm**，拟配 9.5 mm 导向芯轴。只有供应商材料强度、疲劳曲线、腿部折弯应力和样件试验齐备后才能判断应力裕度与寿命。20 mN·m 预载是设计输入，尚非供应商保证。

## 已验证的空间边界

`spring_body_clearance_envelope.ply` 是**封闭圆柱形线圈体的保守包络**，不是可生产弹簧。它包围外径 12.2 mm 的双弹簧线圈，装配轴向范围为 y=79.0–85.7 mm，中心轴过 `[18.894539, 88.199976, 242.757161]` mm 且平行 +Y。每只厂家公式自由体长 3.15 mm；两个体长共 6.30 mm，包络另留 0.40 mm 隔片空间，**没有再为端圈、挡圈及其公差分配长度**。

`spring_body_study.json` 对最终 R29 装配中的 1,193 个刚体在 HOME 做了精确网格体积交集检查，线圈体包络无交集；与头顶壳和新下头壳的 3.45 mm 外扩体也无交集。对现有金属嘴部载体，在 0–10° 每 0.25° 的 41 个姿态均无 3.45 mm 外扩体交集。利用载体顶点离转轴最大 179.640 mm，姿态间最远位移不超过 0.391915 mm，因此只针对**线圈体与该载体**、精确网格和刚体转轴，可得到连续角度名义净空下界 **3.0580858 mm**。线圈真实钢丝尚未建模，所给圆柱包络比线圈体更大；这项证明仍不包括弹簧腿、固定/转动锚点、挡圈、螺钉、柔性线束及制造公差。

现有固定架在 y≈72.6 mm 截面有两处左侧 Ø2.2 mm 孔，中心约 `(x,z)=(11.394,234.757)` 和 `(11.394,250.757)` mm；转动耳在 y≈76.5 mm 截面有四处 Ø2.2 mm 孔，中心围绕嘴轴呈 12 mm 节圆。这只是可利用接口的测绘。没有完成导向芯轴与转动耳的螺钉叠层、固定弹簧腿如何越过转动耳、可装配工具通道、端圈保持方式及固定架孔边强度设计。钢丝安装时的相位和收紧方向也未验证。现有转动耳前端到线圈体起点约 2.3 mm 的轴向名义空隙不能视为完成公差设计。

因此该方案 **不是 R29 已安装件**，不能用线圈体净空替代完整弹簧总成的干涉证明，也不能把无弹簧轨迹的解析力矩抵扣当成重新求解的行走试验。下一步须完成金属导向芯轴、两条固定腿和两条转动腿、螺钉及挡圈的原生 CAD，验证 0–10° 全行程的全零件/工具通道和公差，取得弹簧厂受载寿命与预载实测，再在含新增质量和弹簧模型的机器人上重算四工况。

再生：`PYTHONPATH=work/r12-motion/python-deps:work/rk-mechanics/python-deps:work/r18-leg-hip-covers/review python3 work/r29-mouth-counterbalance/build_study.py`。报告中的 SHA256 绑定运行时 R29 选择件；若选择件变化，必须重算。

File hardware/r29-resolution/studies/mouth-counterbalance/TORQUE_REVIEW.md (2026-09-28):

# Conditional mouth torsion-spring study

This is a separate **feasibility calculation**, not a change to the frozen R29 walking evidence or the active **0.05 Nm** mouth structural guard. The unsprung R29 design remains blocked because all four simulated walks require 0.05837–0.05925 Nm peak and roughly 0.05667 Nm RMS from the mouth motor while it holds closed.

A proposed pair of closing torsion springs uses **0.7 mm wire**, **11.5 mm mean coil diameter**, **3 active turns each**, assumed steel modulus **200 GPa**, and assumed pair preload **0.020 Nm** at closed. [Gutekunst's manufacturer handbook, §1.4.4, pp. 20–21](https://www.federnshop.com/download/pdf/Gutekunst-Federn-1x1-2013-E.pdf) gives the torsion-spring moment-rate relation. With these assumptions, the pair's calculated rate is **0.04349638 Nm/rad**. The proposed passive closing torque is `−0.020 − 0.04349638 × mouth_angle_rad` Nm, or **−0.027592 Nm** at 10°.

Subtracting that ideal torque from the *saved* actuator samples of each unsprung R29 walk gives approximately **0.03834 Nm peak** in all four cases, below 0.05 Nm at every saved 20 ms sample. This is an analytical replay, not a closed-loop simulation with spring mass, friction or a real torque limit. The old report's integration-step peak and 20 ms joint bounds can suggest a conditional ~0.03925 Nm upper value **only if** the unsaved integration-step actuator torque stayed negative. That sign has not been proved for every step, so it is not a certification.

With the head at HOME and base level, static mouth motor torque including the hypothetical spring changes from **−0.03612 Nm at 0°** to **−0.02439 Nm at 10°**. A finite static grid samples three positions on each of four permitted head axes, base roll −18.3/0/+18.3°, and mouth 0/2/5/8/10°: **1,215 poses**. Its largest absolute residual is **0.03920 Nm**, at neck pitch +5°, head pitch −15°, all other head angles and base roll 0°, mouth closed. This grid does not prove a continuous combined-pose envelope or moving-head dynamics, and some combined head extremes may be geometrically unqualified.

The [machine-readable calculation](analytical_torque.json) hashes the four frozen R29 traces, bound joint intervals, model/contract, runtime guard and analysis script. The spring wire, modulus and preload remain design assumptions. Coil-only nominal clearance has been preliminarily checked by the mechanical designer, but **spring legs, anchors, screw stack, rated material stress/fatigue, mass/inertia and complete 0–10° CAD clearance are not frozen**. An installed mechanism must be drawn and inspected before a new 0.05 Nm integrated nominal run is credible; the original R29 blocked result remains authoritative until then.

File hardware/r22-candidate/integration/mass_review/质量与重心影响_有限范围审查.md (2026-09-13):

# R22 质量与重心影响：有限范围审查

本报告只给可追溯的局部名义变化、明确材料假设下的范围，以及重心敏感性。**不生成新整机质量、COM 或惯量，不改 R20/R21 整机模型或原生 PCB，也不把几何检查转成平衡放行。**

## 已有质量账与附件变化

基线是 `work/r20-walking-fix/dynamics/release_v4/verified_models/model_contract_contact4.json`。独立重加 501 条质量及一阶矩，与合同的 4.195093550 kg、HOME COM [1.804277505, 0.094721300, 17.424621374] mm 一致。这些是源工程估计，未实物称重。

| 已有电气项 | 源质量 | 源 HOME COM (mm) |
|---|---:|---|
| Entry | 33.152265 g | [29.5, −14.75, 281.5] |
| TDK Power | 62.203020 g | [−33.435500, 1.557079, 44.540436] |
| Regen | 16.496128 g | [31.564500, −33.755421, 49.540436] |

三项已经包含在基线里，不能把新板实体再次整项添加。已有器件的真实质量分配、五个 Entry 顶插替换的质量、焊料、线尾及共享安装/线束预算未逐项闭合，因此不能用裸板估算替换完整电气行。

Entry_mount manifest 的 13 个被替换零件，与 R20 的对应行逐名核对：旧 13.735365 g，新 12.270838 g，名义差 −1.464528 g。用每件真实 CAD 中心和材料质量重算，这一项单独造成的 HOME 全机 COM 变化约 [−0.02827, +0.00056, −0.09628] mm。

Power_cap_mount 新附件名义 2.438567 g，不含原已计入的 C101 电容；其中编织绑带 0.30 g 是待称重预算。附件名义中心为 [−29.354071, −3.622211, 73.167396] mm。两组附件合计毛增量 +0.974039 g，单独导致的 HOME COM 变化约 [−0.04636, −0.00160, −0.06383] mm。这仍是局部名义账，不是整机更新；后续必须确定是否抵扣既有共享固定/线束池，不能双计。

## 板材与铜：不能按面积直接推减重

直接读取原 3 板与 R22 2 板的 Edge.Cuts、叠层、实际已铺铜多边形、焊盘、走线、孔环和钻孔，按每层布尔并集去重，再扣孔。原 Entry、TDK、Regen 都是 70/70 µm 铜的两层；新两板是 70/35/35/70 µm 铜的四层。五份原生叠层均总计 1.60 mm，源绝缘介质为 1.44 mm，新板为 1.37 mm。

| 板 | 面积 mm² | 铜（含孔铜）名义 g | 裸板材/铜/阻焊名义 g |
|---|---:|---:|---:|
| Entry_source | 2925 | 3.316 | 11.017 |
| TDK_source | 3900 | 4.403 | 14.718 |
| Regen_source | 960 | 1.009 | 3.484 |
| Entry_R22 | 2184 | 3.621 | 9.067 |
| Power_R22 | 4510 | 7.848 | 19.214 |

原三板裸材合计 **29.218 g**，新两板 **28.281 g**，名义差 **-0.937 g**。铜反而约增加 **2.741 g**。减去绝缘材料所得的名义收益，与新增内层及较大铜覆盖的重量互相抵消。

仅把这一裸材名义差与附件毛增量相加约为 **+0.037 g**，工程上接近零；没有有意义的“整机减重”结论，更不能把该数加到 4.195 kg 并宣称精确新质量。器件、焊料和制造误差足以改变其符号。

计算口径：铜密度 8.96 g/cm³；FR4 名义 1.85 g/cm³；孔铜名义 25 µm，去除铜层自身厚度以减少与平面铜重复计体积。FR4 体积扣钻孔，并为内层蚀刻后的区域补入树脂空间；阻焊以两面各 10 µm、1.2 g/cm³、整外形面积近似，真实开窗会减少其质量。全部器件保守包络体积都没有转成“器件质量”。

为显示估算分辨率，另算条件范围：FR4 密度 1.7…2.0 g/cm³、绝缘体积 ±10%；平面铜厚名义的 80…120%；孔铜体积名义的 50…150%；阻焊每面 5…20 µm、密度 1.1…1.5 g/cm³。让旧/新参数独立取最不利端点，裸材差范围约 **−12.15…+10.19 g**。这是公开假设下的保守情景界，非厂家保证或统计置信区间；尚未计表面镀层、焊料、器件、线尾。不能将其包装成实际产品重量上下限。

## 每新增 10 g 的 HOME 重心敏感性

采用精确附加质量公式 ΔC = Δm/(M+Δm) × (p−C)，此处 Δm=10 g、M=4195.093550 g。位置范围来自实际 PCB/器件本体保守包络，经 manifest 的 R/t 变换到同一个 HOME 坐标系；不含相机/显示偏移、插拔工具及线束预算实体。

| 10 g 位于 | ΔCOM X mm | ΔCOM Y mm | ΔCOM Z mm |
|---|---:|---:|---:|
| Entry 包络 | −0.0114…+0.1122 | −0.0540…−0.0128 | +0.5745…+0.6744 |
| Power 包络 | −0.1097…−0.0579 | −0.0746…+0.0800 | −0.0069…+0.1715 |

这是假设新增质量的灵敏度，不代表已知新增 10 g。高位 Entry 同等质量对全机 COM 高度更敏感。对于其他增量，应重新代入公式；“每 10 g”的线性倍乘只是小量近似。

## Regen 跨侧搬迁的有界影响

只在“保留原 Regen 整组 16.496128 g、仅搬位置”的反事实下计算：源集中 COM 为 [31.564500, −33.755421, 49.540436] mm；新 Regen 原位号映射器件加新增板条的包络外界为 [−40.835501, −31.255421, 37.190431] 至 [−24.035495, 18.744579, 89.540436] mm。

因整体质量不变，ΔC = m/M × (p_new−p_old)。全机 HOME COM 变化外界为 X **−0.2847…−0.2186 mm**、Y **+0.0098…+0.2064 mm**、Z **−0.0486…+0.1573 mm**，欧氏范数保守上界 **0.3853 mm**。包围盒角点不一定可成为真实质量中心，因此这是外界，不是假造的新 Regen COM。

原 16.496 g 还含旧 PCB 的预算，而新版共用一块 PCB，所以这个搬迁界不能再和上述裸板替换计算相加当作实际总结果。确切惯量和每个器件的位置权重仍缺来源。

## R21 可继承与不可继承的结论

可以继续把 R21 的冻结轨迹、关节几何、接触定义、原 501 行质量合同和原控制器作为明确版本的比较基线；相同关节输入下的刚体变换仍可用于新实体几何复核。R21 原报告和视频仍描述其原模型运行。

不能把原 85.00077% 最大负载利用率、单足约 8 mm / 双足约 2 mm 压力中心边距、动态跟踪/滑移/地面反力、实际减摆幅度或不跌倒结果直接移植为 R22 的验证。R21 自身质量、惯量、电机能力和摩擦也未实测；其最小双足目标边距仅 1.999589 mm，不能拿 HOME 的 0.385 mm 搬迁界与它相减来证明安全。高位件和跨侧件会改变各连杆一阶矩、惯量及动态载荷，整机静态 COM 相近也不足以推出同等动态结果。

下一次质量更新应先称完整电气板（含实际焊料、插头和规定线尾）、称新附件，按原位号/分组替换已有电气质量并处理共享预算，再更新相应 jaw_soft/trunk_base 的 COM/惯量。之后沿同一 R21 轨迹重算准静态力矩/压力中心并重跑动态工况。此报告不执行该整机更新。

## 文件与复核

- `mass_COM_bounded_review.json`：完整计算、范围、公式口径、来源 SHA。
- `bare_board_materials.csv`、`bare_material_comparison.svg/.png`：裸材比较。
- `native_copper_inputs.json`：只读导出的五板原生铜几何，未改变原文件。
- `extract_bare_copper.py`、`calculate_review.py`、`write_report.py`：可复算脚本。
- `SHA256.json`：本目录最终文件摘要与源文件摘要绑定。

出处：R20 上述模型合同；`mechanics/entry_mount/manifest.json`、`power_cap_mount/manifest.json` 与实际几何 manifest；原/新原生 PCB；`work/r21-reduced-sway/报告.md` 的结构与扭矩检查范围及 `恢复点.md` 的已有电气预算说明。没有另造厂家逐元件质量。

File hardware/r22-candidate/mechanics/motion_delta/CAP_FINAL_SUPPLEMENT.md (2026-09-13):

# C101 托架最终整板补充：126 件参考与套管 v2

**当前结论：托架已按最终 BM08 顶插 J1、8 条 J1 R5 导线、5 条 P 信号 R5 导线、细化元件/Fab/逐焊盘参考及绝缘套管 v2 重新绑定核验。原托架 README 中“J1 仍在修改、需后续复验”的段落描述的是当时的 113 件快照；该项几何复核现已完成。**

当前依据是 [cap_final_reference_rebind_v2.json](cap_final_reference_rebind_v2.json)、[insulation_subset_extension.json](insulation_subset_extension.json) 和 [latest_verification.json](latest_verification.json)。原 [托架设计 README](../power_cap_mount/README.md) 及其 113 件快照保持历史原字节，便于核对当时的尺寸、材质、质量、加工和物理验收约束；不能把其历史待办误读成当前 Power 引用仍未核。

最终 Power 参考共有 126 件：125 件安装实体/包络和 1 件 J1 拔插预算。15 件托架附件对 125 件安装参考，以及托架自身，共 **1,980 对**完成分类，没有未解释的有限交集。J1 拔插预算另与 15 件托架附件逐对检查，均以 AABB 下界证明 ≥3 mm。

缩短后的两个绝缘套是原 STEP 与 STL 的严格子集。30 个套管/托架配对继承旧的正间隙下界；新套管与各自引脚 STEP 间隙为 0.025 mm，交集为 0。两个套管之外的 124 个 Power 参考逐字段不变，托架几何、材料与质量均未修改。

托架及相关新增几何还进入了完整 R22 增量动态检查：所有存在相对运动的新增配对在 R21 9,773 个源区间内满足 ≥2.2 mm 保守下界。托架与本板参考同属 `trunk_base`，其局部几何关系在这些关节运动中保持不变。见 [动态检查说明](README.md)。

这次补充完成的是最终组合的几何复核。原先的机外装配顺序、绑带预紧/高温蠕变与拉脱测试、实际电容直径及衬垫选配、螺钉公差和拧紧验证仍适用。原 TDK 板到机身主承力安装接口未因本报告自动解决；托架质量和力矩预算也没有被当作实物测量结果。

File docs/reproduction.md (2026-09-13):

# 复算和来源核验

## 小规模复核

在仓库根目录用Python 3运行：

```sh
python3 tools/verify_publication.py
python3 -m pip install -r tools/requirements-analysis.txt
python3 tools/recompute_sway.py
```

第一项逐个验证复制文件的新SHA256、本地KiCad库路径、12种板与原理图完整性。第二项使用仓库内两版实际CAD轨迹、原始固定指标合同与原始sway_metrics.py重新计算侧倾及头壳固定点横摆，核对原结论；不重跑动力学积分和全部几何配对检查。

下载Release文件后，可再执行：

```sh
python3 tools/verify_publication.py --assets /absolute/download-directory
```

仓库原生KiCad设计建议使用生成/检查记录相同的KiCad版本。每板从hardware/kicad的对应.kicad_pro打开，fp-lib-table/sym-lib-table均随板附带；完整原检查报告见docs/pcb。这里没有因上传而重新制造、缩板或清除原43项警告。

## 完整历史复算

1. 下载并校验R13.7结构包和R13.8更新包。
2. 将R13.7内“工程快照”内容（work与outputs）恢复到新的工作根目录。
3. 将R13.8内“工程更新”内容合并到同一根目录。
4. 按原始说明安装数值库、KiCad、Blender及必要外部运行环境。执行前查看脚本中的ROOT/路径；部分历史渲染或打包脚本保存了原开发机绝对路径，必须在个人工作副本中配置成本地路径，不能直接当作可移植一键流程。

精选原代码放在reference/work中，保持字节及原目录关系；这里未包含所有网格、历史状态、运行环境和中间结果，完整依赖以Release包及其索引为准。上面的便携减摆复核入口接受仓库路径，不要求原开发机路径。

原始索引放在provenance/original，均为字节原样副本。它们描述原工作根目录和原SHA，历史绝对路径仅为来源证据；不要把它们解释为GitHub链接。面向阅读的docs另做路径转换，未收进Git的历史材料链接指向Release，由原始索引定位包内文件。所有转换都记录在provenance/path-conversions.json；source-manifest.json同时保存原SHA和发布副本SHA，没有拿原SHA冒充改写后的摘要。

完整包内仍有未通过目标的候选和历史资料；判断正式基线应以原CURRENT_DESIGN.json、final_review_index.json及当前README为准。任何数值通过都不升级physical_approved/manufacturing_approved。

## 大文件策略

Git只存便于浏览和复核的源码与报告，大模型和原包使用Release资产。依据 [GitHub大文件说明](https://docs.github.com/en/repositories/working-with-files/managing-large-files/about-large-files-on-github) 与 [Release配额](https://docs.github.com/en/repositories/releasing-projects-on-github/about-releases)，仓库单文件低于100 MiB，Release每项低于2 GiB；此仓库不依赖Git LFS。

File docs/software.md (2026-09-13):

# 驱动、交互、部署与训练

本仓库包含已交付的R8软件源，实际入口是 [rk_runtime](../software/r8/rk_runtime/README_R8.md) 和 [camera_vla](../software/r8/camera_vla/README_相机与上位机VLA.md)。它们是旧R8 profile的工程软件，不代表当前R20/R21结构已经完成软件适配或实机验证。

| 用途 | 入口 |
|---|---|
| Dynamixel 15轴、IMU、电源与50Hz控制 | [microduck_rk](../software/r8/rk_runtime/microduck_rk) |
| 交互、语音与本地API | [README_INTERACTION](../software/r8/rk_runtime/README_INTERACTION.md) |
| INA226/ADS1115采样及RUN门控 | [README_POWER](../software/r8/rk_runtime/README_POWER.md) |
| RK3576 BSP、SAI1及音频 | [BSP说明](../software/r8/rk_runtime/deploy/cm4-bsp/README.md) |
| 三种电机、14策略轴的训练树生成 | [prepare_training.py](../software/r8/rk_runtime/microduck_rk/prepare_training.py) |
| 相机/VLA、人工示教和HTTP协议 | [camera_vla](../software/r8/camera_vla/README_相机与上位机VLA.md) |
| 原软件验证记录 | [R8_software_verification.json](../software/r8/rk_runtime/reports/R8_software_verification.json) |

原记录报告213项运行时测试与56项相机/协议测试，以及合成输入的固定上游训练树生成、BAM CPU路由检查。它们是历史软件边界测试；本次整理没有重新完成ARM64目标内核编译、板端加载、音频/UVC/WiFi并发、GPU训练、真实示教、实测BAM拟合或策略上机验收。

训练依赖固定上游 [microduck_rl 29e887ec](https://github.com/pollen-robotics/microduck_rl/tree/29e887ecfbf5d37144759e5a9f8a176dfb83d547)和 [BAM 62bd8ce](https://github.com/Rhoban/bam/tree/62bd8ce12154340be97e06f7f41a0ca8f116d967)。完整训练框架、Python环境、模型权重与外部服务凭据没有打进此仓库。依赖清单与生成参数见原README。所有标定模板保持null/false，没有生成新的motion_approved策略。

仅在开发机检查导入及离线测试时，从各软件目录按requirements安装依赖，再使用原测试入口。实际inspect/commission会短时开启受监督电源，commission会改电机寄存器；按原说明先完成真实台架条件，不能把它们作为普通源码验收命令。R20/R21的557件结构、关节安装、质量惯量和运动边界须重新绑定并验收。

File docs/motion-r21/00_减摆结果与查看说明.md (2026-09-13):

# R21 / R13.8 减摆步态与PCB复核

基于同一套557件结构、名义质量4.195094kg、RK3576核心板与既定电机能力假设，完整四步实际仿真中的身体侧倾摆幅减少 **28.60%**，上头壳固定点左右跨度减少 **28.62%**。原有四步数值验收标准在四种工况下全部通过。结构尺寸、板形、安装孔、电机及扭矩上限沿用R20冻结基线。

这是慢速数值仿真交付。先前设定的身体40%／头部30%优化目标**均未达到**，记录保留原门槛；未进行实物、正常步速、热、低电量持续扭矩或制造验收。

## 摇摆原因与本轮调整

上一版控制参考主动要求机身向左右倾斜约23–24°，实际机身对参考的最大跟踪误差不到1°。因此主要摆幅来自换重动作本身。上方头壳离机身转动中心较远，同样的角度会产生更大的横向位移。

本轮重新求解双足站姿、左右换重、抬脚、前移与落地。按真实足底支撑多边形的面积质心计算，两脚横向距离由171.367mm降至140.466mm，缩窄18.03%；这来自真实关节正向运动学。准备站姿的脚外展参数由15°调整为约27.974°，屈膝与髋/踝配合也一起调整。全脚实体在初态的最窄横向材料间距约4.634mm，不能把它当作全运动最小三维间隙。

当前每腿没有踝关节侧倾轴，脚底姿态、机身姿态与关节负载存在耦合，减摆仍受这些实际机构约束。本轮保持完整脚底、零件比例和质量模型，头部没有另加反向摆动来隐藏躯干侧倾。

## 实际完整四步对照

所有摆幅取各自完整原始实际轨迹的世界坐标，不使用相机、显示横移或阶段重采样。头部测量点固定为同一个上头壳封闭网格的体积中心，既不是整个头部的质量重心，也不是相机画面的中心。

| 指标 | R20 | R21 | 变化 |
|---|---:|---:|---:|
| 身体侧倾总摆幅 | 46.736 ° | 33.369 ° | -28.60% |
| 上头壳固定点左右跨度 | 257.834 mm | 184.045 mm | -28.62% |
| 机身根位置左右跨度 | 36.331 mm | 23.365 mm | -35.69% |
| 身体左右转向总摆幅 | 22.484 ° | 3.906 ° | -82.63% |
| 机身根位置上下跨度 | 8.250 mm | 9.136 mm | +10.74% |

R21实际侧倾范围为−16.130°至+17.239°；时间加权平均侧倾0.806°，起终侧倾约0°。较小的峰峰值没有依靠持续偏身取得。头部前后跨度约增加3.16mm，机身上下跨度约增加0.89mm，这些变化也保留在原始记录中。

四步实际时间由174.847s增加到195.442s，约增加11.78%。两只脚各迈两步、每步参考前移10mm；名义仿真最终左右脚分别前进20.223mm和20.096mm。它仍属于慢速验证动作，不能据此宣称已达到日常行走速度。

| 工况 | 最大机身跟踪误差 | 最大关节跟踪误差 | 实际受力足最大滑移 | 左／右净前进 | 原四步数值标准 |
|---|---:|---:|---:|---:|---|
| 名义工况 | 0.499° | 0.236° | 0.834 mm | 20.22 / 20.10 mm | 通过；零饱和 |
| 积分步长减半 | 0.499° | 0.234° | 0.817 mm | 20.28 / 20.15 mm | 通过；零饱和 |
| 地面摩擦系数0.5 | 0.500° | 0.236° | 0.824 mm | 20.24 / 20.12 mm | 通过；零饱和 |
| 足底9片接触划分 | 0.560° | 0.170° | 0.439 mm | 20.06 / 20.10 mm | 通过；零饱和 |

滑移补充检查按实际保存的足底法向力大于2N分组，保留计划抬脚阶段仍有短暂接触的记录，不把“计划卸载”当成实际完全离地。名义工况最低足底点的实际抬脚峰值至少3.276mm。四种工况的轨迹、接触记录和验收明细均随更新包交付。

## 结构与扭矩检查的范围

参考轨迹含8399个样本、582段关节直线路径。检查使用完整557件装配：141个选定姿态做全零件材料检查，全部582段逐段检查105219对跨刚体零件。并行只分配原始请求，段、关节值和时间逐条核对，无抽稀或漏段。

实际名义轨迹检查包含9773个关节范围区间，覆盖781767个积分步，累计1,028,305,287项零件对与区间组合。独立复核核对覆盖记录、轨迹端点、关节变换和原始STEP。与R20相比，没有新增未分类的材料穿透。

原先72对参考窄间隙或未完全定性接口、34对实际名义接触/参考表示仍明确保留。原两处颈部网格微残差按原STEP零公共体积核定；两处同一根线的尾端与参考走线表示交叠分别命名记录。这些结果**不是整机全部间隙或柔性线束已经合格**。原六处腿/电池碰撞目标和新左髋连杆在本轮指定检查中没有复发；实际区间的材料分离证明不等于每个区间都已证明2.2mm间隙。

地面检查使用真实源网格：8399个参考样本和9774个实际样本中，555件非脚垫零件均未穿地。实际最小足架离地2.456mm，鞋壳7.560mm；TPU最大数值压入0.544mm仅是接触模型结果，未作为真实弹性压缩验收。

按501条质量来源独立复算重力与关节力矩，参考单足最大利用率约85.00004%；全部给定负载分配最大约85.00077%。单足压力中心边距约8mm；双足分配采用每脚2mm目标，插值后最小1.999589mm，保留这个数值边界。包含惯性的前馈与实际控制另由上述四种工况验证，电机上限和质量/重心仍是未经实测的工程输入。

四步从明确的新准备站姿初始化，两个周期在关节空间闭合并在世界坐标中连续前移，实际积分中不重置机身。旧准备站姿到新站姿的过渡动作单列为候选；从q=0 HOME自主起步尚未取得同等级完整验证，不能随这四步一并放行。

## 查看与复算

- [Microduck_R21_实际减摆对照](<https://github.com/ldcyes/OpenDuck/releases/download/r13.8-simulation-20260913/Microduck-R21-actual-comparison.blend>)
- [R21_完整实际四步_约24倍速](<https://github.com/ldcyes/OpenDuck/releases/download/r13.8-simulation-20260913/R21-four-steps-24x.mp4>)
- [R20_R21_同参考阶段_对照](<https://github.com/ldcyes/OpenDuck/releases/download/r13.8-simulation-20260913/R20-R21-phase-comparison.mp4>)

Blender保留原R20的静态整机、头部安装对照、原实际四步三个场景，并增加R21实际四步、同实际时间对照和同阶段对照。零件仍可分别选择与隐藏。对照相机和比例固定，横向排版位移与物理世界轨迹分开。模型保存后重新打开核验源网格、全部动画键和独立关节变换；视频是有明确倍率的预览，完整采样保留在模型中。

同实际时间视图只比较两版都有数据的共同时间段；同阶段视图显示各自实际秒数。正式幅值始终用完整原始轨迹，不能从任意一段预览估计。

本更新包提供完整可直接打开的Blender模型、新轨迹、控制/前馈生成程序与检查证据。复算脚本所需的旧结构源沿用R13.7“工程快照”，本包“工程更新”合并到同一工作根目录；逐项来源与补充文件见随包索引。这些是仿真控制源，不代表已下载并调通RK3576实机。

## PCB清单、DRC与面积

[全部PCB功能、主要芯片、尺寸及原生设计入口](<../pcb/01_全部PCB功能与主要器件.md>)；[DRC与缩板评估](<../pcb/00_PCB检查与缩板结论.md>)；[独立PCB完整检查包](<https://github.com/ldcyes/OpenDuck/releases/download/r13.8-simulation-20260913/PCB-R13-review.zip>)。

共12种自制PCB、13块用板，LEG5左右各一块，总板框面积166.81cm²。KiCad 10.0.6按原工程规则运行ERC、重铺铜DRC、未连线及原理图对应检查，12种均为0；另把原来忽略的规则启用后出现43项警告：38处焊线/测试点装配占位边界、5处载板过孔中心问题。逐对象复核没有发现新增断路，仍需补装配定义和整理走线。

缩板优先考虑65×45mm的5V入口板，再评估65×60mm舵机电源板与32×30mm回生控制板的合并；58×45mm核心板载板已经四层且受模块/连接器限制。现有孔位、线束、散热与承流铜形成实际边界，本轮未生成经重排复验的更小尺寸或制造板。

当前557件装配只定位了7块自制PCB，回生、两温保、IMU、功放和麦克风这6块尚待详细安装；U2D2和相机也未完成独立安装实体。相关8组估算质量约63.856g已经计入运动模型，补准确CAD与实测质量时应替换原预留，避免重复计重。模型内的现有板形与本次原生电气保持一致，PCB复核没有改变本轮减摆比较的质量和安装基线。

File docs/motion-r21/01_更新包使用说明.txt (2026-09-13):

本包是 R13.7 的步态与检查更新，结构件、PCB板形、安装接口和电机能力参数沿用同一冻结基线。

模型文件可直接打开，已内含完整零件与实际运动；无需先解压旧包才能查看。
复算脚本需要旧 R13.7 包的“工程快照”，再把本包“工程更新”全部内容（含work与outputs目录）合并到同一根目录。沿用文件逐项列在“沿用基线文件索引.json”，新文件逐项列在“文件清单与检查状态.json”。数值库/Blender运行时需按工程记录安装。

PCB独立检查包：PCB_功能_DRC与尺寸复核_2026-09-13.zip，内含全部12种原生板图、原理图、BOM和两轮检查。本次没有生成缩小后的PCB或替换制造文件。

已完成的是慢速数值仿真检查；不是正常步速、硬件低电量、热、强度或实物行走合格证。准备站姿过渡另列候选，不随完整四步的数值结果一并放行。

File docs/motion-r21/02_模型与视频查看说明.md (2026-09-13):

# R21 减摆模型与视频

R21 完整四步的实际仿真记录显示：躯干侧倾峰峰摆幅减少 28.60%，上头壳固定点横摆减少 28.62%。原定 40% / 30% 减幅目标均未达到。模型保留 R20 的全部 557 件 CAD，质量与电机能力上限不变，没有用相机跟随或头部反倾替代躯干减摆。

| 完整原始实际采样指标 | R20 | R21 |
|---|---:|---:|
| 实际积分时长 | 174.84650 s | 195.44175 s |
| 躯干侧倾负峰 / 正峰 | -22.828° / 23.908° | -16.130° / 17.239° |
| 躯干侧倾峰峰摆幅 | 46.73591° | 33.36922° |
| 上头壳固定点 Y 峰峰摆幅 | 257.83441 mm | 184.04505 mm |
| 根部 Y 峰峰摆幅 | 36.33114 mm | 23.36500 mm |
| 侧倾时间加权均值 | 0.75237° | 0.80578° |

这里的头部测量点是同一上头壳原始闭合网格的固定体积中心，不是整头质量重心，也不是随姿态变化的包围盒中心。所有摆幅均来自完整原始实际记录；不使用相位显示重采样、并排横移或截短视频重新计算。

## 六个场景

打开 `Microduck_R21_实际减摆对照.blend`，从顶部场景选择器切换：

1. `01_完整装配_557件_静态`：保留的 R20 完整装配。
2. `02_头部安装_旧与新对照`：保留的头部安装修订对照。
3. `03_实际自由积分_四步行走`：保留的 R20 完整实际记录。
4. `04_R21实际积分_完整四步`：R21 全部 195.44175 秒实际记录。
5. `05_R20与R21_同实际时间`：相同真实经过时间，显示共同的 0–174.84650 秒。R21 余下部分在场景 04 / 06 中完整保留。
6. `06_R20与R21_相同步态阶段`：对齐 30 个相同参考控制阶段，两侧各显示自己的真实时钟。参考“卸载”阶段名不等于接触力已为零，不能当作实测接触事件同步。

对照视图均为 R20 在左、R21 在右，固定相机、相同比例。并排横移使用独立显示父对象，不进入物理坐标和摆幅指标。场景 04 / 05 的秒数为 `(帧 − 1) / 40`；场景 06 的显示轴对应 R20 秒数，R21 实际秒数由单独时间对象给出。

模型分类有电机 15、结构与支架 78、PCB 与电气 215、外壳与覆盖件 50、五金与绝缘 157、独立参考包络 42 个对象，共 557 件。215 个电气对象包含板体、器件和接插件，不代表 215 块 PCB。用集合的可见性按钮查看内部，独立参考包络默认隐藏；不要把供应商最大包络当作实际实心材料。

## 视频与回读

`R21_完整实际四步_约24倍速.mp4` 展示完整 R21 记录；`R20_R21_同参考阶段_对照.mp4` 展示完整阶段对照。视频每约 2 秒显示时间采一帧，以 12 fps 播放；阶段对照的 R20 显示时钟约 24 倍速，R21 按阶段变速，两个实际时钟均标出。视频用于快速观察，完整细节保留在模型全部采样关键帧中。

两段视频分别为 99 帧 / 8.25 秒、89 帧 / 7.4167 秒，均包含最后实际姿态。最后一段取样间隔不足 2 秒，所以“24 倍速”为近似值。清晰字幕栏仅覆盖顶部原说明文字；时钟逐帧来自渲染记录，未缩放或裁剪下方模型，也未修改 Blender 文件。视频已逐帧解码，并检查开头、中间和末尾画面的文字及整机可见性。

模型保留全部 9774 个 R21 原始实际采样。相位视图另加 25 个显示插值点；4 个距原采样过近的额外显示阶段界不另设键，以免 Blender 的近邻合并覆盖原始采样。最大显示界时间差为 0.361625 ms。真实阶段 JSON、原始采样和物理幅值保持原值。

`readback.json` 重新打开最终模型，验证原 R20 三场景、所有源网格、隐藏状态、335 条动画曲线的全部键以及独立正向运动学。`independent_raw_sway_audit.json` 另外以直接角度公式和逐样本源运动学复核完整摆幅，不依赖显示相机或相位重排。

## 范围

这仍是慢速、模型假设下的仿真，不是实物、正常步速、受载、热或低电量行走验收。四工况通过原数值条件；新路径没有增加原检查中的碰撞集合，但参考 / 实际几何中既有的 72 / 34 个未证或窄间隙对仍明确保留，不能读成所有材料分离或全部间隙均已通过。完整来源与独立验证入口由 `visual_delivery_index.json` 绑定；失败模型和运行时试验仅保留在本地诊断目录，不作为通过结果交付。

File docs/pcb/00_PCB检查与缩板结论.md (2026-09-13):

# PCB 绘制复核与缩板评估

2026-09-13；基于当前 R20 装配和 R13 原生电气源。已完成12种自制板、13块用板的复核。**可以继续做紧凑布局，但目前没有经过重排与复验的新板尺寸，不能把现有 PCB 等比例缩小。** 本轮评估没有改变减摆仿真所用的板形、质量和安装接口。

全部板的功能、主要芯片、连接器、尺寸、固定孔和原生原理图/PCB/BOM入口见同包《全部PCB功能与主要器件》。外购 RK3576 核心板、U2D2、BMS、TDK功率模块和相机单列；不冒充自制板，也不杜撰未公开的内部IC料号。

## 本次实际运行的检查

使用 KiCad 10.0.6，在已核字节一致的独立工程副本上运行 ERC、重新铺铜后的 DRC、全部走线错误、原理图与PCB对应检查及全部严重级别报告。原生 PCB、原理图、本地库、规则和其余公开文件共810项来源哈希在结束后再次一致。

**按现有工程声明的规则：12种板全部 ERC 0、DRC 0、未连线 0、板图不一致 0。** 没有启用保存板文件，原板字节未变。这说明当前连接和已声明几何规则通过，不能据此确认温升、载流能力、USB信号完整性或整机装配合格。

进一步在另一组副本中，把项目原来标为“忽略”的规则类别改为“警告”，其余间隙、线宽、网络类、定制规则和全部铜几何保持原值，得到以下额外结果。`--severity-all` 本身不会把“忽略”类别重新启用，所以必须区分两轮结果。

| 板型 | 原规则 ERC / DRC / 未连线 / 板图一致性 | 启用原忽略规则后新增警告 |
|---|---|---|
| 主保险 Main_Fuse | 0 / 0 / 0 / 0 | 2项缺装配占位边界 |
| 舵机电源 TDK_Power | 0 / 0 / 0 / 0 | 4项缺装配占位边界 |
| 5V入口 Entry_5V | 0 / 0 / 0 / 0 | 8项缺装配占位边界 |
| 回生控制 Regen | 0 / 0 / 0 / 0 | 9项缺装配占位边界 |
| 65°C温保 | 0 / 0 / 0 / 0 | 0 |
| 75°C温保 | 0 / 0 / 0 / 0 | 0 |
| RK3576核心板载板 | 0 / 0 / 0 / 0 | 11项缺装配占位边界；5项走线端点未对准过孔中心 |
| LEG5腿部配电（同板×2） | 0 / 0 / 0 / 0 | 2项缺装配占位边界，每种板只检查一次 |
| HEAD3头部配电 | 0 / 0 / 0 / 0 | 2项缺装配占位边界 |
| IMU姿态板 | 0 / 0 / 0 / 0 | 0 |
| AMP功放板 | 0 / 0 / 0 / 0 | 0 |
| MIC麦克风板 | 0 / 0 / 0 / 0 | 0 |

共43项额外警告：38项缺庭院（KiCad的装配占位边界），5项过孔中心问题；没有新增短路、未连线或板图不一致。5项涉及载板的 CORE_5V 和 SYSTEM_5V 电源网。具体位置、对象和原始日志在检查包中，不能写成“所有规则都零警告”。这些项目需要逐项补图或核定端接/探针空间，不能随意画小框再宣布装配检查通过。

逐对象复核进一步确认：38项为29处焊线端和9处测试点，没有缺失芯片或插接器本体的庭院。按唯一板型计，10个焊线端已有局部成形/焊锡包络、17个只有背侧短尾、载板2个输入焊线端尚无局部包络；测试点需定义探针空间。5项走线警告均已用实际线宽、过孔外径和钻孔证明存在正面积名义铜接触，其中3条细短线被同网宽线包含。因此需整理走线和补装配定义，不能把这些警告直接称为断路，也不能因此认定工艺与载流合格。详见《43项警告逐对象复核》。

## 面积与压缩空间

按真实 Edge.Cuts 板框计算，13块总面积为 **16681 mm²，即166.81 cm²**。不含外购核心板、BMS和模块内部PCB；两块LEG5分别计面积。这个数字不是整机外壳占地，也不是可削减面积。

| 优先级 | 现有板 / 面积 | 可行方向及明确约束 |
|---|---|---|
| 优先评估重排 | Entry_5V：65×45mm，2925mm²，占总面积17.53% | 重新排列8组控制/温度/握手连接器、采样与5V电源功能区，评估四层布线是否能减少绕线和占地。现有四孔中心框59×39mm，若孔位和板边安装座均不变，无法明显缩小；需同步修安装座与插拔通道。电源热铜和Kelvin采样路径仍需保留。 |
| 次优先评估系统合并 | TDK_Power 65×60mm + Regen 32×30mm，共4860mm²，占29.13% | 评估把回生控制放入舵机电源载板，减少一组板间连接与一套支架；是否能减少总面积，必须以实际布局验证。回生脉冲、采样、栅极驱动及热源位置需一起设计，外置耗能电阻保留独立散热。TDK现有四孔中心框59×54mm，不能只裁板边。 |
| 优先保留现接口 | CM4载板：58×45mm，2610mm²，占15.65% | 已是四层板。受核心板、三组100针连接器和四个通栓孔约束，大面积缩减空间较小。任何改变须同步核心板配合、散热器/PEEK堆叠、USB布线与安装通道。先处理本次发现的5项过孔中心警告，再考虑局部优化。 |
| 仅在确有安装收益时重排 | LEG5×2 + HEAD3：3880mm²，占23.26% | 主要受JST EH插头、13个熔断支路、AWG16端接和大电流铜限制。两层成品铜厚、主干/支路宽度、孔铜及压降要求不能按缩放比例降低。改变板形会影响LEG5工具井、头板支柱和已检查线束。 |
| 低优先级 | IMU + AMP + MIC + 两温保板，共1656mm²，占9.93% | 可在各自安装设计时整理紧凑布局，但需保留传感器刚性固定、麦克风声孔/密封声道、功放散热，以及温保芯片与被测部件的真实热接触。为省少量面积把温保移离热源不成立。 |
| 随电池固定件一起审查 | 主保险：30×25mm，750mm²，占4.50% | 左侧留白含固定孔及支撑功能，不能直接裁去。保险可拔空间、AWG16焊线、线夹和电芯正极到首保险≤100mm的已批准要求继续有效。 |

以上为依据原生布局、面积份额和已知机械接口作出的工程评估，**未给未经验证的“缩小后可制造尺寸”或节省百分比承诺**。若孔位、插头位置和线束出口必须完全不动，显著缩板空间会进一步收窄。

外购部件也给出了明确尺寸边界：Radxa CM4官方外形为55×40mm；TDK所选i7C模块本体标称34×36.8mm。它们不能随载板缩放，模块本体面积也不等于载板所需总面积。[Radxa官方产品页](https://radxa.com/products/cm/cm4/)、[TDK所选模块官方参数](https://product.tdk.com/en/search/power/switching-power/dc-dc-converter/info?part_no=I7C2W020A120V-P03-R)。

同尺度布局图只画原生封装包围框、焊盘和非金属化孔；未画铜区、配对插头、线束及散热包络。自动提取的铜/焊盘外缘空白也只用于找候选，不能把铜区、固定边和部件包络当成可随意移除的材料。

## 与当前整机和运动设计的关系

当前557件模型中只定位了7块自制板；Regen、两温保、IMU、AMP和MIC共6块尚待详细安装，U2D2和相机也没有对应完整安装实体。它们并非从重量中完全漏掉：最终运动模型已有6板及两外购模块的8组集中质量，共约63.856g（AMP项包含扬声器），但使用了继承预算/目录质量和预留重心位置，并非实测与安装完成。

因此，下一次紧凑布局应把“缩板、安装空间与真实重心”一起闭合。新增准确CAD与实物质量时，要替换已有预留质量并处理共享固定/线束预算，不能再次把整块板重量加一遍。本轮PCB复核与减摆对比保持同一质量基线；当前摆幅改善也不能替代这些尚未完成的安装验证。

建议先补全本次43项警告的对象定义，再对Entry_5V做一个保持功能和元件规格的紧凑布局候选；同时以TDK/回生为第二候选评估合并。候选必须交付实际KiCad文件、重铺铜后的两轮DRC、具体新尺寸、3D插拔/工具通道与电流热核算，之后才能改入当前整机。

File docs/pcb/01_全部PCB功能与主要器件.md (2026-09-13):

# 当前全部PCB盘点（R20装配基线；R21只读复核）

**12种自制PCB、13块实际用板设计**，其中LEG5左右各一块。当前557件装配只定位7块；另6块尚未完成安装。按板外轮廓、含LEG5重复数量合计16681mm²，这不是可削减面积。原理图、板图和BOM共36份源文件SHA全部复核一致。

以下层数、外形和孔径直接来自当前KiCad文件。功能与主要器件结合原理图/BOM和板上MPN复核。详细针网、封装位置、全部孔及SHA在 [机器可读清单](<https://github.com/ldcyes/OpenDuck/releases/tag/r13.8-simulation-20260913>) 和 [原生PCB提取](<https://github.com/ldcyes/OpenDuck/releases/tag/r13.8-simulation-20260913>)。

| 自制板 / 数量 | 尺寸mm / 铜层 | 功能 | 主要芯片与关键元件 |
|---|---|---|---|
| 电池主保险板 ×1 | 30×25×1.6 / 2层 | 把首道可更换熔断保护放在电池正极出口，限制短路故障持续能量。它与 Entry 上的 2 A 逻辑支路保险是不同器件。 | 无有源IC；Keystone 3549-2 MINI 保险座；Littelfuse 0297015.WXNV，15 A / 32 V DC |
| 舵机主电源板 ×1 | 65×60×1.6 / 2层 | 用外购 TDK 升降压模块生成舵机电源，加入输出隔离/反向阻断、过压切断、硬件过流检测及电流遥测。 | Q1 CSD18540Q5B；Q2 CSD18540Q5B；Q3 BSS138；U1 i7C2W020A120V-P03-R；U2 LM74800QDRRRQ1；U3 INA226AIDGSR；U4 INA300AIDGSR |
| 电池入口、5 V 与监测板 ×1 | 65×45×1.6 / 2层 | 测量电池电流，产生逻辑 5 V，并在电池与台架 5 V 之间切换；把温度、过流和运行握手接口集中连接到主控。 | U1 INA226AIDGSR；U2 ADS1115IDGSR；U3 LMZM33603RLRR；U4 TPS2117DRLR |
| 再生制动控制与电流测量板 ×1 | 32×30×1.6 / 2层 | 在舵机减速回灌使母线升高时，模拟比较器驱动 MOSFET 接通外置回生电阻，并记录耗能支路电流。 | Q1 CSD18540Q5B；Q2 BSS138；U1 TLV76050DBZR；U2 REF3312AIDBZR；U3 TLV3201AIDBVR；U4 UCC27511DBVR；U5 INA226AIDGSR |
| 65 °C 回生热板温保板 ×1 | 16×12×1 / 2层 | 作为回生散热板局部过热的硬件后备停机输入。 | U1 TMP302ADRLR |
| 75 °C TDK 温保板 ×1 | 16×12×1 / 2层 | 作为 TDK 模块局部过热的硬件后备停机输入。 | U1 TMP302BDRLR |
| RK3576 CM4 主控载板 ×1 | 58×45×1.6 / 4层 | 为外购 RK3576 CM4 提供机械/电源接口、核心支路限流、USB 静电保护、音视频/传感器连接及恢复测试点。计算处理在外购核心板内。 | U1 TPS259530DSGR；U2 USBLC6-2SC6；U3 USBLC6-2SC6；U4 USBLC6-2SC6 |
| 五路腿部配电板 ×2 | 40×36×1.6 / 2层 | 两块相同硬件分别给左右腿 5 台 XM430 分配电源，并并联分发半双工 TTL 数据。 | 无有源IC；每板 5 × Littelfuse 0448003.MR，3 A；每板 5 × S3B-EH(LF)(SN)；每板 1 × SM04B-SRSS-TB(LF)(SN) |
| 三路颈头配电板 ×1 | 40×25×1.6 / 2层 | 给两台颈/头 XM430 和三台串接的 XC330 分配三路独立熔断电源；三个接口实际带五台电机。 | 无有源IC；3 × Littelfuse 0448003.MR，3 A；3 × S3B-EH(LF)(SN)；SM04B-SRSS-TB(LF)(SN) |
| 六轴姿态传感器板 ×1 | 24×18×1.6 / 2层 | 向主控提供惯性传感数据，用于后续姿态估计；本板本身不是已完成的平衡控制器。 | U1 LSM6DSV16XTR |
| I²S 单声道功放板 ×1 | 28×20×1.6 / 2层 | 将主控数字音频转换为单声道扬声器驱动，并提供麦克风支路连接。 | U1 MAX98357AETE+T |
| 数字麦克风与电平转换板 ×1 | 20×14×1 / 2层 | 采集声音，产生麦克风所需 1.8 V，并在麦克风与主控间转换数字接口电平。 | U1 MMICT5848-00-012；U2 TXU0204PWR；U3 TLV75518PDBVR |

安装孔与外形约束（XY均为原始KiCad毫米坐标；不是整机坐标）：

| 板 | 固定孔与声孔 | 当前安装 / 缩板时必须保留的接口 |
|---|---|---|
| Main_Fuse_R8 | H1 (3,3) φ2.2；H2 (3,22) φ2.2 | 已定位工程参照（未实装验收）。保留两颗 φ2.2 固定孔、MINI 可拔保险座、AWG16 端接与独立线夹空间；电芯真实正极到首保险的已批准总导体上限100mm仍适用。缩板不能破坏15A路径或裸端邻近间隙。 |
| TDK_Power_R8 | H2 (62,3) φ2.2；H1 (3,3) φ2.2；H4 (62,57) φ2.2；H3 (3,57) φ2.2 | 已定位工程参照（未实装验收）。四孔59×54mm固定图样和外购TDK功率模块引脚/本体是主要几何约束；输入输出大电流铜、Kelvin采样、输出反向阻断与Tc散热/探头接口需保留。模块内部不能随载板缩放。 |
| Entry_5V_R8 | H4 (62,42) φ2.2；H3 (3,42) φ2.2；H1 (3,3) φ2.2；H2 (62,3) φ2.2 | 已定位工程参照（未实装验收）。四孔59×39mm；头部既有安装座及8个控制/NTC插头与配对插头通道绑定当前板形。电池测量回路、5V转换和台架切换的热/回流路径不能只按空白面积删去。 |
| Regen_R8 | H3 (3,27) φ2.2；H1 (3,3) φ2.2；H2 (29,3) φ2.2；H4 (29,27) φ2.2 | 尚未纳入当前557件装配，保留旧待安装画廊来源。四孔26×24mm；板尚未在当前557件内安装。外置RH电阻和热片与此板分开，需保留MOSFET脉冲回流、取样分流器Kelvin引线、驱动去耦与AWG16端接。 |
| Thermal_65C_R8 | H2 (14,2) φ2.2；H1 (2,2) φ2.2 | 尚未纳入当前557件装配，保留旧待安装画廊来源。两孔中心距12mm，1.0mm板厚；当前无最终热接触安装。缩小后仍需确定65°C热板接触区域、绝缘、固定压力与热响应，不能仅以板外形尺寸替代测温界面。 |
| Thermal_75C_R8 | H1 (2,2) φ2.2；H2 (14,2) φ2.2 | 尚未纳入当前557件装配，保留旧待安装画廊来源。两孔中心距12mm，1.0mm板厚；当前无最终TDK Tc热接触安装。TMP302B设定及探头与模块真实Tc区的接触/热滞后需要保留和核验。 |
| CM4_Carrier_R13 | H1 (5,6) φ2.7；H4 (52.95,38.98) φ2.7；H3 (52.95,5.98) φ2.7；H2 (5,39) φ2.7 | 已定位工程参照（未实装验收）。四个φ2.7孔来自现有板图，孔排保持47.95mm横距、33mm纵距及右排−0.02mm偏差；与核心板φ2.6孔、4mm/1.5mm/5mm PEEK栈和M2×22通栓同轴。三组100针DF40的位置/朝向/1.5mm配合高度不可同步缩放；USB差分与完整参考地、eFuse热铜和插拔空间同属约束。R20只把旧无孔预览换为真实有孔板体，未改电路、外形或板厚。 |
| LEG5 | H2 (37,16.5) φ2.7；H1 (3,18) φ2.7 | 已定位工程参照（未实装验收）。每块两φ2.7孔为(3,18)/(37,16.5)，不是同一水平线；两块板分别连接左右腿。既有LEG5支架/工具井、5个JST EH3插头、3A支路保险、AWG16电源端接与大电流回流需保留；J6细线地不装以免旁路动力回流。 |
| HEAD3 | H2 (37,12) φ2.7；H1 (3,12) φ2.7 | 已定位工程参照（未实装验收）。两φ2.7孔中心距34mm，当前头架jaw_soft位置已固定；3个EH3接口共带5个电机，不能按3电机缩减容量。应保留移动头颈线束的服务弯、支柱及配对插头空间。 |
| IMU_P0 | H1 (2.8,2.8) φ2.2；H2 (21.2,15.2) φ2.2 | 尚未纳入当前557件装配，保留旧待安装画廊来源。两φ2.2对角孔(2.8,2.8)/(21.2,15.2)，当前无最终安装/传感轴合同。缩板需保留加速度计/陀螺仪的刚性安装、坐标定义、去耦及接头；J2调试口在工程BOM规定为DNP，不能仅凭PCB封装出现认定装配。 |
| AMP_R3 | H1 (2.5,2.5) φ2.2；H2 (25.5,17.5) φ2.2 | 尚未纳入当前557件装配，保留旧待安装画廊来源。两φ2.2对角孔(2.5,2.5)/(25.5,17.5)，当前支架/安装未闭合；5V输入、I²S、麦克风支路及桥接扬声器连接器占边，需保留功放散热与扬声器双端回流，SPK_P/SPK_N均不是地。 |
| MIC_R3 | H1 (2.2,2.2) φ2.2；H2 (17.8,11.8) φ2.2；U1 (2.092,9) φ0.65声孔 | 尚未纳入当前557件装配，保留旧待安装画廊来源。两φ2.2固定孔加U1下φ0.65声孔；声孔不是第三个固定孔。1.0mm板厚、底部拾音孔/外壳声道/密封泡棉和数字时钟隔离需配套，当前尚无实际安装合同。 |

外购模块单列；不加到13块自制板中：

| 外购模块 | 主要电子功能 / 芯片 | 尺寸及当前装配口径 |
|---|---|---|
| Radxa CM4 RK3576 核心板 | 运行Linux、控制与网络/上位机客户端；自制载板提供供电和接口，不含RK3576处理器。 Rockchip RK3576；RK806S-5 PMIC；RTL8211FS(I)(-VS) 以太网PHY；FE1_1S USB Hub；LPDDR4X/eMMC随采购SKU，容量/料号不在本盘点中重新定型 | 源STEP的PCB约54.98×40.02×1.2mm；这是板材范围，不是整模块最大高度。三组100针DF40；四个原厂孔φ2.6。与现有载板、PEEK、散热器耳和M2×22通栓共轴，保持安装位置。 |
| ROBOTIS U2D2 | USB转DYNAMIXEL半双工TTL/RS485；当前使用TTL数据，不供电机动力电源。 封装内USB/串口/收发器具体IC料号未在当前已核资料中确定 | 外壳48×18×14.9mm。当前557件主选择无U2D2独立实体；USB口/TTL插头及固定/工具空间须另外完成。 |
| PCM-L04S30-566（Li-ion 4S） | C0…C4电芯抽头保护及P−回流，和首道15A保险分工不同。 保护IC及MOSFET具体料号未由供应方冻结资料确认 | 60×60×5mm最大包络。当前躯干包络位置已入557选择；真实焊盘、端接、绝缘和固定界面仍需供应方合同。 |
| TDK i7C2W020A120V-P03-R | 产生名义10.8V舵机母线；外侧保护/监测由TDK_Power_R8负责。 模块内部控制IC未单独定型；采购件为完整i7C2W020A120V-P03-R | 开框模块图示34.04×36.83mm（±0.38），高14.35mm（±0.70）；默认引脚3.68mm单列。65×60mm是外侧自制载板。不能重复计为第14块自制板，也不能随承载板同比例缩小；保留Tc区与散热接口。 |
| Waveshare OS05A10 USB Camera (A), 33123 | OS05A10图像传感器输出USB视频供RK3576或上位机视觉/VLA使用。 OS05A10图像传感器；USB桥接IC具体MPN未在所核资料中确认 | 板25×25×1.6mm，总深22.1mm；图示主要外形公差±0.2mm。图上四φ2孔呈21×21mm孔距；镜头和插头深度须保留。当前557主选择没有对应摄像头实体，不能以旧功能表称已安装。 |

12台XM430与3台XC330自带驱动/编码器电子器件；它们属于外购完整舵机，内部板数/IC/制造文件不在本工程自制PCB清单。风扇等产品内部电子亦不按未核数量追加自制板。

当前原生设计入口（均已核SHA，源文件未改）：

| 板 | 原理图 | PCB | BOM |
|---|---|---|---|
| Main_Fuse_R8 | [SCH](<https://github.com/ldcyes/OpenDuck/releases/tag/r13.8-simulation-20260913>) | [PCB](<https://github.com/ldcyes/OpenDuck/releases/tag/r13.8-simulation-20260913>) | [BOM](<https://github.com/ldcyes/OpenDuck/releases/tag/r13.8-simulation-20260913>) |
| TDK_Power_R8 | [SCH](<https://github.com/ldcyes/OpenDuck/releases/tag/r13.8-simulation-20260913>) | [PCB](<https://github.com/ldcyes/OpenDuck/releases/tag/r13.8-simulation-20260913>) | [BOM](<https://github.com/ldcyes/OpenDuck/releases/tag/r13.8-simulation-20260913>) |
| Entry_5V_R8 | [SCH](<https://github.com/ldcyes/OpenDuck/releases/tag/r13.8-simulation-20260913>) | [PCB](<https://github.com/ldcyes/OpenDuck/releases/tag/r13.8-simulation-20260913>) | [BOM](<https://github.com/ldcyes/OpenDuck/releases/tag/r13.8-simulation-20260913>) |
| Regen_R8 | [SCH](<https://github.com/ldcyes/OpenDuck/releases/tag/r13.8-simulation-20260913>) | [PCB](<https://github.com/ldcyes/OpenDuck/releases/tag/r13.8-simulation-20260913>) | [BOM](<https://github.com/ldcyes/OpenDuck/releases/tag/r13.8-simulation-20260913>) |
| Thermal_65C_R8 | [SCH](<https://github.com/ldcyes/OpenDuck/releases/tag/r13.8-simulation-20260913>) | [PCB](<https://github.com/ldcyes/OpenDuck/releases/tag/r13.8-simulation-20260913>) | [BOM](<https://github.com/ldcyes/OpenDuck/releases/tag/r13.8-simulation-20260913>) |
| Thermal_75C_R8 | [SCH](<https://github.com/ldcyes/OpenDuck/releases/tag/r13.8-simulation-20260913>) | [PCB](<https://github.com/ldcyes/OpenDuck/releases/tag/r13.8-simulation-20260913>) | [BOM](<https://github.com/ldcyes/OpenDuck/releases/tag/r13.8-simulation-20260913>) |
| CM4_Carrier_R13 | [SCH](<https://github.com/ldcyes/OpenDuck/releases/tag/r13.8-simulation-20260913>) | [PCB](<https://github.com/ldcyes/OpenDuck/releases/tag/r13.8-simulation-20260913>) | [BOM](<https://github.com/ldcyes/OpenDuck/releases/tag/r13.8-simulation-20260913>) |
| LEG5 | [SCH](<https://github.com/ldcyes/OpenDuck/releases/tag/r13.8-simulation-20260913>) | [PCB](<https://github.com/ldcyes/OpenDuck/releases/tag/r13.8-simulation-20260913>) | [BOM](<https://github.com/ldcyes/OpenDuck/releases/tag/r13.8-simulation-20260913>) |
| HEAD3 | [SCH](<https://github.com/ldcyes/OpenDuck/releases/tag/r13.8-simulation-20260913>) | [PCB](<https://github.com/ldcyes/OpenDuck/releases/tag/r13.8-simulation-20260913>) | [BOM](<https://github.com/ldcyes/OpenDuck/releases/tag/r13.8-simulation-20260913>) |
| IMU_P0 | [SCH](<https://github.com/ldcyes/OpenDuck/releases/tag/r13.8-simulation-20260913>) | [PCB](<https://github.com/ldcyes/OpenDuck/releases/tag/r13.8-simulation-20260913>) | [BOM](<https://github.com/ldcyes/OpenDuck/releases/tag/r13.8-simulation-20260913>) |
| AMP_R3 | [SCH](<https://github.com/ldcyes/OpenDuck/releases/tag/r13.8-simulation-20260913>) | [PCB](<https://github.com/ldcyes/OpenDuck/releases/tag/r13.8-simulation-20260913>) | [BOM](<https://github.com/ldcyes/OpenDuck/releases/tag/r13.8-simulation-20260913>) |
| MIC_R3 | [SCH](<https://github.com/ldcyes/OpenDuck/releases/tag/r13.8-simulation-20260913>) | [PCB](<https://github.com/ldcyes/OpenDuck/releases/tag/r13.8-simulation-20260913>) | [BOM](<https://github.com/ldcyes/OpenDuck/releases/tag/r13.8-simulation-20260913>) |

现有13个独立熔断支路连接15台电机：LEG5两板各5路；HEAD3的前两路各1台XM430，第三路为3台XC330串接。3A保险额定值不等于主动限流，也不是持续运动电流能力的实物证据。

RK3576在外购核心板上，自制CM4载板没有另一颗RK处理器。R20头部修订只取消重复压条、补五金，并将旧无孔载板预览换为已有4个φ2.7孔的实体；当前4层R13电路版未改。隐藏的核心板MAX包络仍不是芯片和PCB的真实材料。

6块待安装板为Regen、Thermal65、Thermal75、IMU、AMP、MIC；它们的制造源存在，旧画廊提供查看，但不在当前557件机器人内部。U2D2和相机也没有纳入当前557主选择的实际独立实体。不能从有原理图或图库推出整机已经完整安装。

根代理已完成两轮规则检查：[当前项目规则、重铺铜及全走线检查](<https://github.com/ldcyes/OpenDuck/releases/tag/r13.8-simulation-20260913>)中，12种板的ERC/DRC/未连线/原理图对应差异均为0；[额外启用原忽略规则的诊断](<https://github.com/ldcyes/OpenDuck/releases/tag/r13.8-simulation-20260913>)出现43项警告（38项缺courtyard、4项CORE_5V及1项SYSTEM_5V走线未对准过孔中心），没有新增短路、未连线或原理图对应差异。两轮规则集合不同，不能写成无条件“所有DRC零问题”。逐板结果已绑定本清单相同PCB SHA。

缩板可行性由根代理另行报告。板子面积缩小若改变孔位、B2B接口、插头/线束通道、散热或高电流铜，会引出相应机械与电气复核；不按任意百分比保证可缩。制造、上电、温升、音频、线束和实体行走仍未验收。

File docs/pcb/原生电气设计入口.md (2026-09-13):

# 当前原生电气设计入口

本包原生板、图、规则和本地封装/符号库与当前公开工程逐字节一致。用于编辑和复现电气检查；本包没有生成缩小后的PCB或新的制造放行。完整3D装配继续使用当前R20模型。

| 板型 | 数量 | PCB | 原理图 |
|---|---:|---|---|
| AMP_R3 | 1 | [PCB](<../../hardware/kicad/AMP_R3/Microduck_Audio_AMP_R3.kicad_pcb>) | [SCH](<../../hardware/kicad/AMP_R3/Microduck_Audio_AMP_R3.kicad_sch>) |
| Entry_5V_R8 | 1 | [PCB](<../../hardware/kicad/Entry_5V_R8/Microduck_Entry_5V_R8.kicad_pcb>) | [SCH](<../../hardware/kicad/Entry_5V_R8/Microduck_Entry_5V_R8.kicad_sch>) |
| IMU_P0 | 1 | [PCB](<../../hardware/kicad/IMU_P0/Microduck_IMU_3V3_Prototype.kicad_pcb>) | [SCH](<../../hardware/kicad/IMU_P0/Microduck_IMU_3V3_Prototype.kicad_sch>) |
| MIC_R3 | 1 | [PCB](<../../hardware/kicad/MIC_R3/Microduck_Audio_MIC_R3.kicad_pcb>) | [SCH](<../../hardware/kicad/MIC_R3/Microduck_Audio_MIC_R3.kicad_sch>) |
| Main_Fuse_R8 | 1 | [PCB](<../../hardware/kicad/Main_Fuse_R8/Microduck_Main_Fuse_R8.kicad_pcb>) | [SCH](<../../hardware/kicad/Main_Fuse_R8/Microduck_Main_Fuse_R8.kicad_sch>) |
| Regen_R8 | 1 | [PCB](<../../hardware/kicad/Regen_R8/Microduck_Brake_Control_R8.kicad_pcb>) | [SCH](<../../hardware/kicad/Regen_R8/Microduck_Brake_Control_R8.kicad_sch>) |
| TDK_Power_R8 | 1 | [PCB](<../../hardware/kicad/TDK_Power_R8/Microduck_TDK_Power_R8.kicad_pcb>) | [SCH](<../../hardware/kicad/TDK_Power_R8/Microduck_TDK_Power_R8.kicad_sch>) |
| Thermal_65C_R8 | 1 | [PCB](<../../hardware/kicad/Thermal_65C_R8/Microduck_Thermal_65C_R8.kicad_pcb>) | [SCH](<../../hardware/kicad/Thermal_65C_R8/Microduck_Thermal_65C_R8.kicad_sch>) |
| Thermal_75C_R8 | 1 | [PCB](<../../hardware/kicad/Thermal_75C_R8/Microduck_Thermal_75C_R8.kicad_pcb>) | [SCH](<../../hardware/kicad/Thermal_75C_R8/Microduck_Thermal_75C_R8.kicad_sch>) |
| Microduck_CM4_Carrier_R13 | 1 | [PCB](<../../hardware/kicad/Microduck_CM4_Carrier_R13/Microduck_CM4_Carrier_R13.kicad_pcb>) | [SCH](<../../hardware/kicad/Microduck_CM4_Carrier_R13/Microduck_CM4_Carrier_R13.kicad_sch>) |
| Microduck_PDB_R13_LEG5 | 2 | [PCB](<../../hardware/kicad/Microduck_PDB_R13_LEG5/Microduck_PDB_R13_LEG5.kicad_pcb>) | [SCH](<../../hardware/kicad/Microduck_PDB_R13_LEG5/Microduck_PDB_R13_LEG5.kicad_sch>) |
| Microduck_PDB_R13_HEAD3 | 1 | [PCB](<../../hardware/kicad/Microduck_PDB_R13_HEAD3/Microduck_PDB_R13_HEAD3.kicad_pcb>) | [SCH](<../../hardware/kicad/Microduck_PDB_R13_HEAD3/Microduck_PDB_R13_HEAD3.kicad_sch>) |

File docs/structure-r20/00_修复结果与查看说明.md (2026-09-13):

# R13.7 结构与步态修复

已消除本轮确认的腿壳、头部重复压条及补查发现的左髋连杆冲突；统一最终重量后，四项慢速四步数值试验均满足预先声明的跟踪、滑移和限幅标准。当前是工程设计与仿真交付，尚无样机；正常步速和制造资格未取得。

[完整三场景 Blender](/mnt/c/users/administrator/documents/codex/2026-09-05/microduck-x20/outputs/Microduck_R13_7_步态与头部安装修订/模型/Microduck_R20_修订与实际行走.blend) · [实际行走视频](/mnt/c/users/administrator/documents/codex/2026-09-05/microduck-x20/outputs/Microduck_R13_7_步态与头部安装修订/视频/R20_实际四步_约12倍速.mp4) · [完整修订包](/mnt/c/users/administrator/documents/codex/2026-09-05/microduck-x20/outputs/R13_7_结构与步态修复.zip)

## 当前统一设计

继续使用 RK3576 核心板与已接受的外形、覆盖件和脚尺寸。HOME 外形高度约 570.393 mm，557 件，名义质量 **4.195093550 kg**；质量模型为 501 条记录，仍含估算。相对原 4.194478291 kg 净增约 0.615 g。新增头部五金从原预留五金质量池分配，没有重复增加整组质量。

工程内部修订号为 R20，公开查看包为 R13.7。当前选择唯一入口为工程快照中的 `work/r20-walking-fix/assembly_final/assembly_selection.json`；其状态保留创建时“待验证”字样，最终复核结论以同目录上一级的 `final_review_index.json` 为准。旧 assembly、assembly_v2、candidate_v1/v3 与旧试验数据均不是当前设计。

## 修了什么

| 原问题 | 修订 | 证据 |
|---|---|---|
| 6 对膝部/大腿与电池前后壳相交，原最大已查网格交体 115.465 mm³ | 重新求连续双脚步态，加入双侧真实零件避碰、承重踝力臂约束及平滑定时 | 772 条参考关节线段逐对检查；最终实际积分区间另审 |
| 两根头部前压条与散热器安装耳各穿透 63.291 mm³ | 取消重复压条，保留原散热耳，补齐 4 组 M2×22 与 4 组 M2.5×10 贯穿五金 | 新增/表示修订件 15,718 对 HOME 检查；57 个原始正交体逐项核原 STEP，无新增意外材料穿透 |
| 补查发现左髋侧摆支架与原连接杆相交，原 STEP 见证约 0.149 mm³ | 改左髋杆中段走向，保留 φ10 杆径及两端原板、孔和轴向末段 | 新杆对全部 556 件检查，551 个跨刚体对覆盖 772 条参考线段，均达到 2.2 mm 目标 |
| 原自由机身约 12.155 秒失去跟踪 | 加入重力/运动前馈与双脚负载分配；两段左脚前移各放慢 1.5 倍 | 15 个关节的扭矩上限未提高，四项实际自由基座积分均完成 |

左髋关键两对额外检查了参考侧摆角两端各增加 3° 的整个区间：电机侧连续网格间隙证书最低下界 2.325 mm，支架侧 3.275 mm；最不利有限姿态的原 STEP 电机侧间隙 2.491 mm。连续结论针对来源绑定的三角网格，原 STEP 结果为独立有限姿态佐证。

头部载板显示模型补入已有 KiCad 的真实安装孔；本次没有修改 PCB 电路或制造孔轴。核心板实际厚 1.2 mm、载板厚 1.6 mm；M2 裸夹层加两端垫圈为 17.9 mm，M2×22 的公差预算露出为 1.61–3.49 mm。具体尺寸和装配顺序见头部图纸。

## 四项实际自由机身结果

| 试验 | 机身姿态误差° | 最大关节误差° | 最大支撑脚滑移 mm | 最长连续限幅 ms | 左/右脚净前进 mm |
|---|---:|---:|---:|---:|---:|
| 主仿真，0.25 ms、μ=0.8 | 0.9374 | 0.3256 | 1.2141 | 0.25 | 20.341 / 20.452 |
| 积分步长减半 | 0.9339 | 0.3260 | 1.2165 | 0.00 | 20.310 / 20.471 |
| 摩擦降至 μ=0.5 | 0.9365 | 0.3258 | 1.1012 | 0.00 | 20.237 / 20.345 |
| 相同足底划分为 9 片 | 0.8820 | 0.2565 | 0.9161 | 0.00 | 20.598 / 20.133 |

每项均为左右脚各两步，连续积分约 **174.85 秒**，每脚合计前进约 **20 毫米**。这是很慢的验证动作，不能解释为已具备日常行走速度。基座只在初始时定位，之后没有固定、重置或施加牵引力。主仿真右踝仅一个 0.25 ms 积分步到达 1.0 N·m 限幅，其余三项没有达到限幅。

预先声明的指标为：机身和关节误差各≤3°、支撑脚轮廓点滑移≤3 mm、连续限幅≤20 ms、每脚至少两步且净前进≥15 mm、每次抬脚最低点的峰值净空≥2 mm。峰值扭矩与跟踪按每个积分步统计，足位/滑移/离地按 20 ms 保存点计算。

静态独立复核使用最终 501 行质量，最大扭矩利用率 **85.0679%**，名义剩余约 **14.93%**；重心投影到真实足底多边形边缘的最小距离 **7.9275 mm**。最终质量相对旧轨迹搜索目标“≤85% / ≥8 mm”有小幅偏差，两个旧目标并未严格同时满足。动态标准保持原值；此静态余量不能替代受载、低电量或热稳态测试。

接触离散也作了修正：原仿真器的单块足底网格在某些姿态只选到对角线接触点，造成数值滑转。现将同一个已声明的 2 mm 足底接触代理棱柱划分为 4 片，再用 9 片复核。闭合布尔核对了并集、边界和底顶高度等价，质量、惯量、摩擦及接触参数没有改变；这只是接触代理的几何等价，不是 TPU 材料试验。[MuJoCo 3.3.7 官方碰撞器源码](https://raw.githubusercontent.com/google-deepmind/mujoco/3.3.7/src/engine/engine_collision_convex.c)

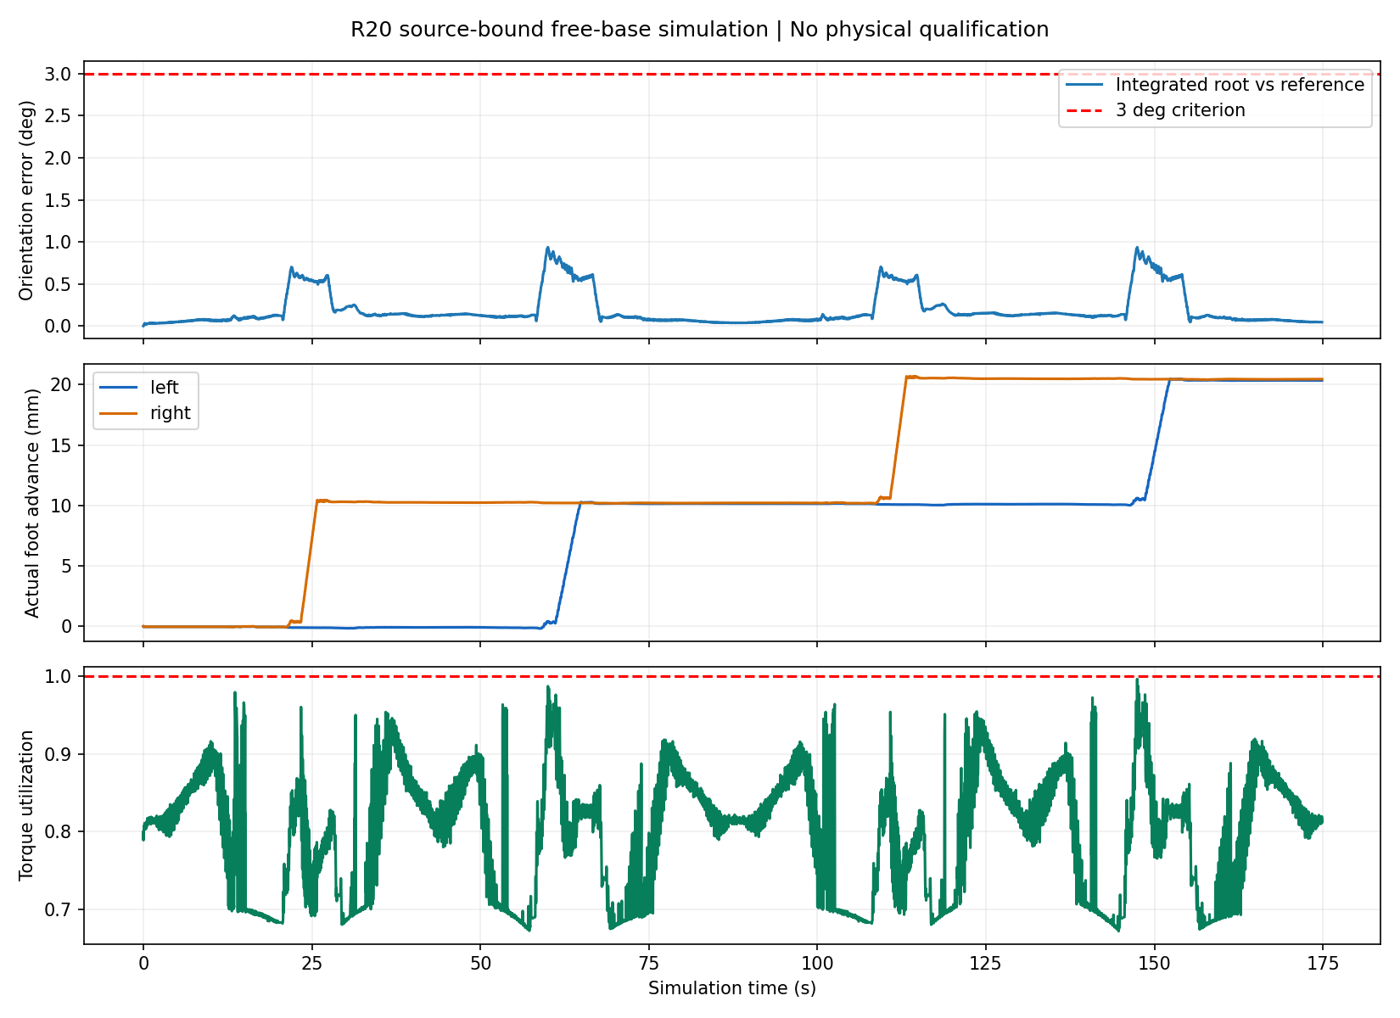
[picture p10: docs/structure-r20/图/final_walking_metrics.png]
实际动力学指标


## 干涉检查覆盖与保留问题

参考路径对整机 105,219 个跨刚体零件对、772 条关节线段进行了连续间隙证明与明确失败记录，共 81,229,068 个零件对—线段请求。未改动的 556 件严格核对原几何、坐标及关节树后复用证书，新杆全部重新检查。静态同刚体接触另列，没有通过忽略父子零件来消除干涉。

主仿真的实际自碰后检覆盖 **699,386 个积分步、8,743 个关节角度区间**，共 **919,929,717** 个跨刚体零件对—区间请求。已证明材料分离 919,632,455 个，其中 911,273,513 个同时达到 2.2 mm。该包络覆盖所有数值积分端点及其关节直线连接，不是数学连续时间解或实体全过程证明。三项敏感性试验通过动力学标准，未各自重复完整 CAD 区间证明。

**原有 72 对参考窄间隙/未证明接口，以及实际包络中 34 对未证明接口仍明确保留。** 它们包含电机名义配合、线束参考等，不能统称为全机零重叠或所有间隙合格。实际后检的 4 个正交体见证已核原 STEP：两处颈部网格微残差对应原 STEP 交体为零；另外两处是同一根导线的直尾与 HOME 路由参考重叠，线束弯曲及耐久尚未建模验证。

地面另用真实 557 件网格检查：参考 7,666 姿态、实际 8,744 姿态，555 个非 TPU 件均未穿地。实际最低脚框净空 2.346 mm、鞋壳 7.466 mm、非脚部零件 31.476 mm。**实际 TPU 接触垫最大穿地 0.654 mm**，保留为接触模型差异；未将它认定为已经验证的橡胶压缩。地面结果为保存姿态采样，不是全过程连续地面证明。

## 图纸、装配与后续验收

图纸文件夹提供头部堆叠/五金和左髋新杆接口、加工、装配与载荷筛查。左髋 4 条 φ3×25 mm 装配工具轴包络已对全部 557 件检查，无相交；不含手柄或操作者手部。头部工具检查采用图示开放工位及装配顺序，未宣称闭壳可维修。

髋杆保留整体 7075 CNC 候选定义，机加工刀具和工序的几何可达性以髋杆制造报告为准。专用细颈刀的侧向进入路径最低名义间隙约 0.070 mm，余量很小，刀具跳动、挠度及夹具公差尚未核实，不能据此放行加工。尺寸公差、CAM/夹具、材料批次、局部应力和疲劳仍须制造前验收。保守载荷筛查不是有限元或实物载荷通过，不能把名义 φ10 截面直接当成已具备疲劳安全系数。

在现有“暂不制作实体”的安排下，下一阶段仍需：实际电机方向/零点标定、低电量持续扭矩和温升、TPU摩擦/压缩、鞋扣保持力、线束活动余量，以及干装—电气台架—吊架受载—行走验收。仿真 HOME 角与控制逻辑不能直接作为已标定的实体驱动文件。当前未作真实制造、上电或外包下单。

## 查看与文件来源

Blender 顶部场景菜单：01 完整装配；02 头部安装旧与新对照；03 实际自由积分。右侧对象列表可按 PCB、电机、结构、覆盖件和五金选择/隐藏。中键旋转、滚轮缩放；空格播放/暂停，拖动底部时间轴定位。视频约 12 倍速，动画插值只供查看，碰撞结论来自独立几何报告。

工程快照保留当前 557 件的 STEP/STL 来源、修订图纸、选型/质量清单、仿真控制逻辑和轨迹、接触模型及各项复核数据。完整 Blender 可直接查看；重新计算还需兼容的 Blender、Python CAD 和 MuJoCo 运行环境，依赖运行时不在本包中。包内保留来源中的历史诊断文件时，仅用于追溯，以各 final_delivery_index 指定的最终路径为准。原头部早期审计记录使用旧版区间算法，清单明确将其旧 SHA 映射到字节相同的保留 v1 文件；原报告保留，最终轨迹审查另绑定当前算法。

完整文件清单记录 SHA-256；交付时另核归档 CRC、复制一致性和原 R13.4 五份基准未变。文件一致性通过不等于所有装配、制造或实体行走资格通过。

头部安装修订对照

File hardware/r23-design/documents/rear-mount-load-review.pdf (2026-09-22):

R23 / v10　工程设计评审；无制造或实物放行 | 1 / 2

# 后载体 v10 · 载荷与截面评审

冻结几何、质量分配与方向范围

绑定 candidate_v10 的 7 件 STEP；冻结 manifest SHA256： a1bf4b9a1c1ba6f2c72561787dbb3e8c7510f9207c117fc08eef9e93a9cb681d

冻结前后全部零件字段一致，状态/来源字段更新。逐件 STEP SHA、R/t/link_frame 及连续芯检查见结构 JSON。所有质量为设计筛查输入，不能替代最终总装称重。

冻结 quick 25.92615848 g 重基，退休旧鞋、M2x8、VMQ、5413；PEEK 路径 26.120873 g，加入适配件及 INPUT 螺钉后 27.596918 g。全组 COM world = [-25.546683, -37.632315, 61.972108] mm。现有线桥上限 3.247075 g 只加至共享 INPUT 惯性；SSHS 厂家名义 0.11 g、工程上限 0.121 g。

108 工况：5g / 10g / 3 N@全组COM，各配六个有符号世界方向与独立 J01 0.2 N 六向。共享 INPUT 另加两现装线各 0.2 N 轴向正负，共 432 工况；旧每线 5 N
为裸桥台架项。力球界允许主力/J01任意独立方向；共同惯性保持同向，未假定角加速度。
任意方向球界 | 5g | 10g | 3 N验证
PEEK 力矩范数上界 N·mm | 33.837 | 62.465 | 67.484
共享 INPUT 力矩范数上界 N·mm | 53.160 | 92.242 | 99.996
PEEK 单颗附加拉 / 剪力上界 N | 12.608 / 8.000 | 23.412 / 14.785 | 25.434 / 16.046
INPUT 单颗附加拉 / 剪力上界 N | 15.110 / 8.740 | 27.025 / 15.894 | 30.086 / 17.118

实际连续芯与含直接横剪的名义模型

PEEK 根部 L 芯 A=14.9384 mm²；另取其中完整 1.48×7.58 mm 矩形统一算弯曲和扭转。所有采用的连续芯差集均为严格 0。仅对完整矩形加入直接横剪 1.5V/A，与 Saint-Venant 扭剪幅值保守相加；不对孔槽净面套用该系数。

3 N 名义模型（MPa） | 六轴，含直接剪切 | 任意方向球界
PEEK 根部降阶矩形 VM | 18.251 | 20.486
7075 低过渡芯 VM | 18.633 | 27.588
7075 高梁芯 VM | 10.621 | 12.998
7075 耳颈芯 VM | 54.827 | 57.030

限于给定传递力矩的棱柱梁模型；不能作为分支支架真实最大应力。两耳分流、短梁约束翘曲、孔边/凹角 Kt、接触刚度及疲劳另验。旧结构 JSON 的 VM 字段只含正应力与扭剪；完整值引用球界报告。

R23 / v10　工程设计评审；无制造或实物放行 | 2 / 2

# 有限接触、残余预紧与首件门槛

明确极性的六分量平衡

两螺钉拉/剪＋真实有限压面完整平衡 Fx/Fy/Fz/Mx/My/Mz，最大残差 2.843×10^-14。PEEK 双侧条带 Y28.01..28.39 / 31.61..31.99、Z7.61..14.39，每条 2.5764 mm²；INPUT
四个耳帽均实核在材料内。原更长左条带不完整，已拒绝。该反力构造不等于真实弹性压力分布。

按真实共享面 A=24.19734578 mm²
及非对称惯性（含避让/角缺口）建立线性面压；INPUT 为两个 OD3.8 / ID2.2 金属环。等残余预紧 P 下
C=2P-Fx，在包含实际面的外矩形角点检查不张开。下表是该条件模型的充分值，不是装配设定值或通用必需下限。
任意力球：每颗等残余预紧 N | 5g | 10g | 3 N
PEEK 两新螺钉 | 21.940 | 40.696 | 43.911
INPUT 两原轴螺钉 | 27.977 | 50.183 | 51.321

不张开不等于不滑。仿射摩擦牵引场平衡面内力和扭矩；以残余 75 N/颗举例，3 N球界所需充分 μ 为 PEEK 0.813、INPUT 0.980；100 N/颗为 0.451、0.477。未采用或证明任何 μ，也未建议如此预紧 PEEK。零摩擦承压路线须验证 D2.2 对 M2 的名义径向 0.1 mm 余隙、位移、孔壁承压及循环损伤。

薄环、螺纹和热态允许窗口尚待实测

下侧 SSHS 实际头承压面积 8.530139876 mm²，上侧 8.765043504 mm²
；下环截去 2.680%，孔到下边净距 0.7 mm，沉孔底仅 1 mm。不可按完整环或 2.2 mm
厚法兰核算。外载螺钉拉力还需叠加实际预紧，再验该薄座、PEEK牙峰/拔出/劈裂与金属耳孔。

PEEK 几何插入 3.0 mm，完整成形有效牙 ≥2.5 mm 须量规/首件剖验。热态残余预紧下界与螺纹/面压可承受的上界必须同时成立，允许窗口目前 OPEN。用实际最高温度与保温时间测残余力、滑移、角位移及联合载荷后损伤。

NBK 官方 SSHS：SUSXM7、A2-50；不能继承 INPUT 的 A2-70。SSHS-M2-4 表列最大 0.18 N·m 不是 PEEK 建议扭矩。官方网页由 web 工具读取成功，普通下载 403；精确 URL/短摘录/表项已转录，未冒称原始 HTML 归档。

Victrex450G 官方 2026-03：23°C拉伸模量4000 MPa；125/175°C弯曲应力85/19 MPa；120°C压缩应力70 MPa。均为典型树脂数据，非机加工件许用，缺高温模量/长期蠕变/松弛曲线。不得以85 MPa除以上述VM宣称安全系数或通过。
复核文件与适用边界

详表：candidate_v10_structural_review.json；v10_six_component_joint_equilibrium.json；v10_contact_geometry.json；v10_contact_and_sphere_ review.json。来源：NBK_SSHS_official_web_evidence.json、Victrex_450G_official_2026-03.pdf。所有哈希及路径见 v10_review_index.json；详细中文说明见 README_v10_zh.md。全域碰撞、五流道与装配扫掠由主代理独立检查。

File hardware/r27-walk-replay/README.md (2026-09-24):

# OpenDuck R27：R26 四步行走运动回放

[English](README_EN.md) · [R26 覆盖件与完整静态模型](../r26-cover-first/README.md)

本版把已保存的 R21 自由根数值积分轨迹驱动到 R26 的完整装配。时长 195.44175 s、四步、9,774 个真实保存姿态；Blender 中 1,224 项装配几何可逐件选择。视频将这段过程约 24 倍速展示。**这是 R26 外形的运动回放，不是按 R26 质量重新求解的动力学试验。**

四步运动中段

[完整可交互 Blender](https://github.com/ldcyes/OpenDuck/releases/download/r27-r26-four-step-replay-20260925/OpenDuck-R27-R26-four-step-replay.blend) · [四步视频](https://github.com/ldcyes/OpenDuck/releases/download/r27-r26-four-step-replay-20260925/OpenDuck-R27-R26-four-step-preview.mp4) · [工程证据包](https://github.com/ldcyes/OpenDuck/releases/download/r27-r26-four-step-replay-20260925/R27-walk-replay-evidence.zip) · [SHA256](https://github.com/ldcyes/OpenDuck/releases/download/r27-r26-four-step-replay-20260925/SHA256SUMS.txt)

运动模型新增场景 `07_R27_R26四步运动回放`，保留 R26 原有静态装配和对比场景。打开后选择场景 07，在时间轴上播放或逐帧查看；动态场景使用实际自由根和 15 个关节的保存数据，不是凭图像插值生成的任意步态。

## 干涉判断

后续已对 R26 两块新罩直接重跑区间检查；详见 [R28 干涉复核](../r28-r26-interference/README.md)。其中最小保守证明间隙仅 0.015 mm，不能按 2.2 mm 制造目标放行。

R26 仅缩短两块大腿罩，且两块新的 STEP 实体均为旧罩实体的子集。两罩对应的旧版连续运动检查各包含 57 组动态配对，在 9,773 个积分区间内没有未解决的动态穿透；其余 1,191 项刚体零件与关节变换保持原状。因此，同一轨迹下 R26 不会比已检查的 R25 刚体装配新增穿透。旧版装配的 110 项命名安装接触沿用其逐项分类；这不等于全机器人任何姿态都没有冲突。

31 项自由颈部线束没有纳入旧刚体区间检查。视频中它们按显示用近似方式随躯干移动，不能用于判断线束在弯折、拉力和公差下的间隙。既有嘴部与下头壳约 8.75° 起的冲突仍保留；本次四步轨迹嘴部指令为 0°。

## 动力学边界

R21 原动力学模型为 4.195094 kg；R26 结构估计为 4.443060 kg，相差约 247.97 g。原轨迹的脚底接触、力矩和稳定性结果不能转写为 R26 新动力学验收。仍须以 R26 实测质量、惯量、电池电压、柔性线束和真实地面重新求解并做台架及行走验收。**本文件不授权样机上电行走。**

[运动来源与碰撞证据](verification/analysis.json) · [Blender 全部关键帧和位置回读](verification/readback.json) · [构建及检查程序](sources)

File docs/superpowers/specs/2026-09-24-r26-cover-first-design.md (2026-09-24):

# R26 大腿覆盖件 A 方案实施设计

用户于2026-09-24明确选择已发布《腿部比例与电机筛选》的A方案。该报告是本设计的已审阅方案依据；不再询问是否采用A或是否增加高度。

## 范围与基准

以 `work/r25-bottom-head-entry/assembly_selection.json` 及其完整Blender为装配基准。仅替换左右 `R18P_*_thigh_photo_triangle`。保持两侧关节轴、腿长、真实商品电机尺寸、承载连杆、脚、固定支架、螺钉、螺母和垫圈位置。目标是减少膝下遮挡，不声称增加了实际腿长。头部左侧孔永久闭合B方案继续作为单独已授权事项，不混同为本次腿部变更。

## 外形与接口

将下缘从膝轴下约27.2 mm收至约10 mm，名义目标恢复约17 mm垂直露出量。优先沿现有圆角三角罩参数重画下角，并与原实体求交，保持既有面法线、2 mm主壁、外观曲率语言和安装面。

新件应是旧覆盖件的实体子集；该条件成立时，在相同关节变换和相同其它几何下不会新增碰撞，原有未闭合碰撞仍保留。不可仅以包围盒重叠作为穿透证明。若子集条件不成立，执行对新添体积的完整静态及连续运动复核，不能沿用子集结论。

保留两个安装孔、定位沉孔、OD9垫圈承压凸台及其周围至少原设计的完整支承。覆盖件固定孔中心至新外缘目标不低于7 mm；若约10 mm下缘目标不满足孔边距，优先保留固定强度并记录实际下缘。表面锐边倒圆或保留原圆角；不得改变2 mm名义主壁来获得外观效果。

报告中的4 mm侧向内收是检查候选。它不能在保留支架与螺钉位置的条件下直接实施：应先核对定位凸台、螺钉有效长度和支承面。若需要重做夹座承载结构，本次先保持侧向安装位置，清楚报告未内收原因；不扩大为未经设计的承载机构改造。

## 必须交付的证据

1. 新旧源文件哈希、左右零件唯一替换关系，15个关节数据逐项未变；每个保留件的坐标和来源未变。
2. 原生STEP有效且为单一闭合实体；精确三角网格闭合、定向、无新增非流形边，导出/重读体积与包络一致。提供毫米STEP、STL及打印主文件3MF。
3. 原生实体 `new minus old` 体积不高于数值容差，并用独立网格方式复核。容差写入报告；不能将显著外溢记作接触豁免。
4. 两孔、沉孔与承压区域的原生实体差分为零或仅数值容差；使用真实紧固件和台架装配阶段工具通道复核。孔边距与最小主壁单列。
5. 新件对R25其它安装件的HOME检查；名义接口接触必须按具体配对分类。相同轨迹下用子集证明解释连续碰撞增量，并保留旧几何未闭合项。子集证明不等于新整机全面无碰撞证明。
6. 根据材料密度重新核算两盖质量差及整机HOME重心变化；不重新宣称动态平衡、扭矩、续航或实际行走通过。
7. 更新完整独立Blender装配，回读验证部件来源及变换。提供正交前/侧视、新旧同尺度对比，不把被删除的倾斜姿态图重新放回首页。
8. 提供中英文更新说明、装配替换说明及验证摘要，同步OpenDuck；大模型按既有Release方式交付。

## 完成定义

上述设计文件与规定数字验证完成后，状态为工程候选交付。未有样机，制造/物理批准始终为false；不把候选设成已获装机运动许可。新覆件若无法同时满足几何与固定要求，应保留可复现失败证据并修订轮廓，不能只交付效果图。

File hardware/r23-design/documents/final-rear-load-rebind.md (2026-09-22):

# 最终质量与重心：后载体 v10 局部载荷复绑

本报告绑定最终选择器 `a9df66c72faf49bd74b2c5047ffddb117d498ca943c228e131047d6c2ce29ff0` 与最终质量账；1189安装件、17服务/自由态参考。原v10七件STEP、姿态、真实接触面和连续芯逐项同源。旧v10评审、旧9cd680归档均未覆盖；当前旧1N标量比较的脚本及两份JSON另存`legacy_bucket_snapshot/`。本目录使用原v10反力、截面、有限面压和任意力球方法，重新代入最终分组质量及重心，不借用原COM的结论。

|质量传递路径|质量 g|HOME COM X/Y/Z mm|
|---|---:|---|
|最终原后载体桶，含adapter|26.764192058|-25.30812521 / -37.92831086 / 62.90787952|
|PEEK路径，移出adapter|25.943217480|-24.85965902 / -38.03835149 / 63.71085187|
|第二接口，加入adapter与两INPUT螺钉|27.419262639|-25.55007722 / -37.80630005 / 62.25404695|
|现有INPUT桥，仅加在共享INPUT|3.247074932|-19.65545852 / -25.03378920 / 32.59811525|
|共享INPUT总惯性路径|30.666337571|-24.92593133 / -36.45389532 / 59.11395785|

原v10的PEEK26.120872698g与第二接口27.596917858g及其COM是历史输入。最终桶26.764192058g本来包含adapter却不含INPUT桥和两INPUT螺钉，因此不能直接整桶加载到每个接口。两颗SSHS自身质量继续保守归PEEK；adapter及两INPUT螺钉只从第二接口加入；INPUT桥自身只加在共享INPUT。每一行名和质量/COM来源均记录在`Final_Rear_Load_Rebind.json`。这只是同一整机质量账的局部分路，不再增加全机质量。

对5g、10g采用各实际路径的质量和COM，在同一惯性加速度方向下组合。3N静力分别作用于第二接口完整组COM及原26.764192g桶COM，覆盖两种明确的夹具施力位置；静力不虚加INPUT桥10g惯性。每组108个方向工况为三种载荷×六个世界有符号方向×独立J01 0.2N六向；共享INPUT再加两条现装线各0.2N轴向正负，合成432项。任意方向界允许主载荷与J01分别取独立力球；INPUT两线保留实际轴向。5g/10g中桥和后组保持相同加速度，未假定角加速度、冲击放大、柔线弹力或实测分载。

|有限面压模型充分等残余预紧 N/颗|5g|10g|3N@第二接口完整COM|3N@原后载体桶COM|
|---|---:|---:|---:|---:|
|PEEK两颗SSHS|22.050586|40.917717|44.423198|45.808519|
|INPUT两颗螺钉|27.969502|50.168365|51.624369|52.710257|

这些是指定线性面压分布模型保证所选面不张开的充分条件，不是装配扭矩、推荐预紧或接触FEA。实际面保持PEEK24.19734578mm²及INPUT两实际OD3.8/ID2.2环，含v10凹口；按包含实际面的外矩形角点核定。

|同一连续矩形梁模型的任意方向VM界 MPa|5g|10g|3N@原后载体桶COM|
|---|---:|---:|---:|
|PEEK根部降阶完整矩形|10.380339|19.341637|21.558413|
|7075低过渡芯|13.482256|25.136454|28.500598|
|7075高梁芯|6.354382|11.835191|13.371629|
|7075耳颈芯|27.987986|52.014131|58.833253|

同一截面同时计算正应力、Saint-Venant扭转及直接横剪，横剪1.5V/A只用于经原STEP差集证明完整存在的矩形；两种剪切幅值保守相加后计算VM。该名义梁界没有给出整件最大应力：孔边、牙峰、凹角Kt、短梁约束翘曲、接触刚度与局部分流仍未认证。典型PEEK树脂数据不可直接当零件热态许用或用于宣布安全系数。

原后载体桶COM的3N工况下，75N/颗残余预紧时，构造仿射摩擦牵引场所需充分摩擦系数界为PEEK0.902923、INPUT1.070514；100N/颗分别0.486380、0.504580。这些仅是条件敏感性，没有采用或证明摩擦系数，也没有建议把PEEK拧至75/100N。零摩擦构造依赖螺钉/孔壁正承压，D2.2对M2名义径向0.1mm间隙可能被吃掉，不等于零位移。

PEEK下侧头承压面8.530139876mm²、上侧8.765043504mm²，孔到底边净距0.7mm、沉孔底余厚1mm保持。完整有效牙≥2.5mm须量规/首件验证。热态长期残余预紧下界必须与螺纹拔出/劈裂、面压和蠕变允许上界同时成立；目前预紧允许窗口仍OPEN，摩擦、蠕变/应力松弛、循环拆装和疲劳均无实物通过证据。SSHS A2-50不能借用INPUT的A2-70；0.18N·m厂家参考表值也不是PEEK建议扭矩。

独立复核从每个最终质量行直接在世界坐标累加力与力矩，再旋转到两接口，覆盖两组1296个接口/共享反力输入；同时原样回放冻结v10的108/432载荷，验证复用的原函数能重现旧记录。数值残差及全部SHA见`Verification.json`。结论仅为当前来源下条件工程模型复绑，未取得制造配合、预紧、3N/5g/10g实物或整件FEA验收。任一实际质量/COM或接触几何变化须再次复算，不能只按3N标签沿用。

入口：`Final_Rear_Load_Rebind.json`、`Verification.json`、两个COM子目录的完整反力和接触/球界JSON、`DELIVERY_INDEX.json`。旧1N标量记录仅展示历史差异，不定义当前v10唯一容量。

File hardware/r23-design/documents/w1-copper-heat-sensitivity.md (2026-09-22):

# W1 铜损与局部热预算补充

固定电源线避让变长后，热量需要单独计入。105°C电阻应力场景、11.5 A假定电流下，整根W1铜损为 **0.330324413 W**，比旧线增加 **0.103082411 W**。这不是实际线温、平均耗电或持续载流能力的测量。

原局部网络计算转换器、回生件及0/0.61/1.25 W上游热量场景，没有证据将W1明确分配到这些通用热量项，也不包含全机器人所有线束、RK3576、电池和外壳热源。因此不能把风道几何和计算流量相同解释为整机发热或温度不变。

|采用条件|另计上游热量|条件体积流量0.294276 CFM下的平均空气温升敏感性|
|---|---:|---:|
|已有预算确实计入旧W1全铜损|只加0.103082 W|0.674969 K|
|已有预算未计入W1|计入现整根0.330324 W|2.162918 K|

两种情况互斥，不要把整根与增量同时加。表内用ΔT=P/(ṁcp)，热容率0.152721658 W/K，并假定所分配的热量全部进入充分混合的送风。它是平均流体的条件敏感性，不能作为实际入口热点、导线表面温升、回流或公差的上界。

`Converter_W1_Heat_Sensitivity.csv`对原324个转换器条件各做上述两种比较，共648行；所有工况均保持假定W1电流11.5 A，其它效率、局部热阻、环境温度及回流条件不变。增量计入时，原条件电流预算最大减少0.227284 A；若整根未计入则最大减少0.728326 A。这些仍是热阻和送风假设下的比较，不是电气功率与热状态联立求解，更不是新增的连续电流额定值。

W1在i7C稳压前，额外压降还要纳入最低电池输入条件，不能直接从稳压后的5 V头部预算重复扣除。传感器欠读、四项Tc内部基准、真实流量、温升及保护动作仍须样机验收。当前补充没有修改原冻结热网络、线路几何、导线额定值或控制器限值。

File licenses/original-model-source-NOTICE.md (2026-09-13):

# 3D模型来源与许可记录

原始3D模型作者/来源：Pollen Robotics，pollen-robotics/microduck_rl。

固定提交：29e887ecfbf5d37144759e5a9f8a176dfb83d547。

原始模型目录：https://github.com/pollen-robotics/microduck_rl/tree/29e887ecfbf5d37144759e5a9f8a176dfb83d547/src/mjlab_microduck/robot/microduck

原始许可说明：https://github.com/pollen-robotics/microduck_rl/blob/29e887ecfbf5d37144759e5a9f8a176dfb83d547/README.md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

该提交的README将软件与3D模型分开说明：软件为Apache 2.0；3D模型文件标为 **Creative Commons BY-SA-NC**。上游此处未标明具体版本号，本交付不替其指定版本。

本目录的STL、Blender装配及由这些模型生成的预览是模型的派生资料，保留上游的署名、相同方式共享及非商业条件。随附的Apache文本是上游软件许可记录，不能解释为覆盖所有3D模型的商业使用许可。

2026-09-05修改内容：从固定提交获取并核对源STL；制造参考STL坐标由米乘1000转换为毫米；根据MJCF组织Blender父子装配并应用官方软件home姿态；添加预览材质与检查记录。未冒充原版可编辑机械CAD，也未声称得到Pollen的认可。

R2修改：新增保护板边夹与护罩、插头防护仓、开关安装平面及孔、配合顶壳避让、端子护罩；U2D2调整3mm，加入具名电池内部名义外廓及接口需求。所有源资料和R1均只读，未修改。

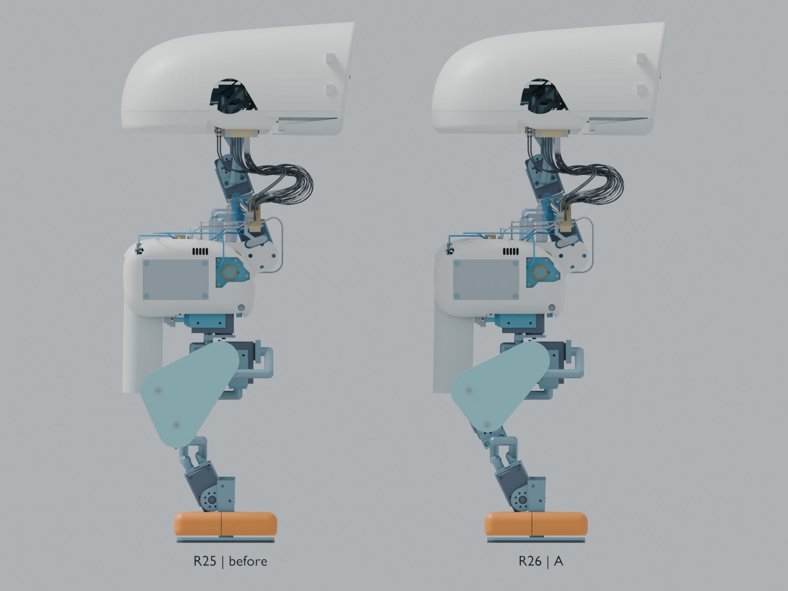
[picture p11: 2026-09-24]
hardware/r26-cover-first/images/03-full-comparison.jpg

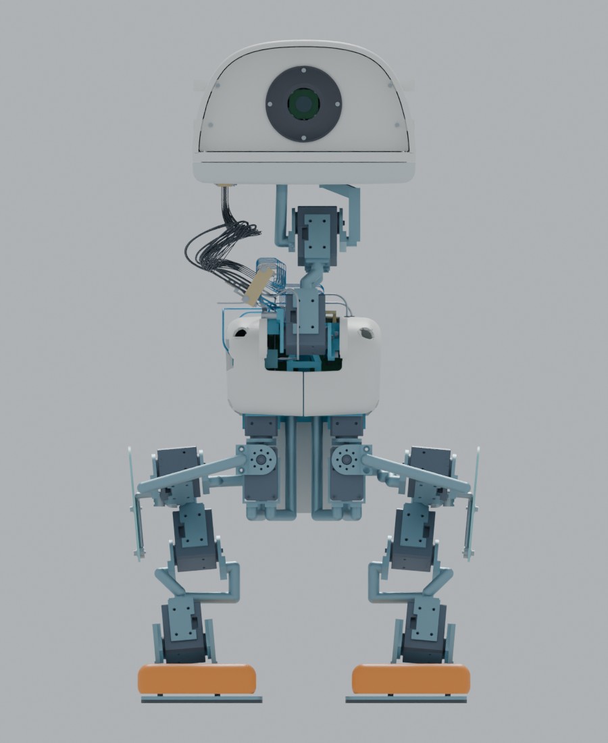
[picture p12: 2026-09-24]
hardware/r26-cover-first/images/01-front.jpg

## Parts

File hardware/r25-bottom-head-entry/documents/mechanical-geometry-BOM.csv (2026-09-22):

name | geometry_instance_count | material | kind | replaces | manufacturing_master_or_step | note
R25_neck_upper_PEEK_comb_housing | 1 | unfilled PEEK Victrex450G-series machining stock | manufacturing_candidate | R23_neck_upper_PEEK_comb_housing | work/r25-bottom-head-entry/mechanics/STEP_毫米/R25_neck_upper_PEEK_comb_housing.step | 几何实例，非新增采购总数；绑带和结头同一物料，导线按独立端号总表
R25_neck_upper_VMQ_comb_installed | 1 | Wacker ELASTOSIL LR3004/40 A/B VMQ Shore A40 typical | installed_deformation_reference | R23_neck_upper_VMQ_comb_installed | work/r25-bottom-head-entry/mechanics/STEP_毫米/R25_neck_upper_VMQ_comb_installed.step | 几何实例，非新增采购总数；绑带和结头同一物料，导线按独立端号总表
R25_neck_upper_PEEK_retainer | 1 | unfilled PEEK Victrex450G-series machining stock | manufacturing_candidate | R23_neck_upper_PEEK_retainer | work/r25-bottom-head-entry/mechanics/STEP_毫米/R25_neck_upper_PEEK_retainer.step | 几何实例，非新增采购总数；绑带和结头同一物料，导线按独立端号总表
R25_neck_upper_retainer_1_washer | 1 | A2 stainless DIN125 M2.5 washer ID2.7 OD6 t0.5 | manufacturing_candidate | R23_neck_upper_retainer_1_washer | work/r25-bottom-head-entry/mechanics/STEP_毫米/R25_neck_upper_retainer_1_washer.step | 几何实例，非新增采购总数；绑带和结头同一物料，导线按独立端号总表
R25_neck_upper_retainer_1_M2x6 | 1 | A2-70 socket screw nominal purchase envelope | purchase_reference | R23_neck_upper_retainer_1_M2x6 | work/r25-bottom-head-entry/mechanics/STEP_毫米/R25_neck_upper_retainer_1_M2x6.step | 几何实例，非新增采购总数；绑带和结头同一物料，导线按独立端号总表
R25_neck_upper_mount_1_front_washer | 1 | A2 stainless DIN125 M2.5 washer ID2.7 OD6 t0.5 | manufacturing_candidate | R23_neck_upper_mount_1_front_washer | work/r25-bottom-head-entry/mechanics/STEP_毫米/R25_neck_upper_mount_1_front_washer.step | 几何实例，非新增采购总数；绑带和结头同一物料，导线按独立端号总表
R25_neck_upper_mount_1_rear_washer | 1 | A2 stainless DIN125 M2.5 washer ID2.7 OD6 t0.5 | manufacturing_candidate | R23_neck_upper_mount_1_rear_washer | work/r25-bottom-head-entry/mechanics/STEP_毫米/R25_neck_upper_mount_1_rear_washer.step | 几何实例，非新增采购总数；绑带和结头同一物料，导线按独立端号总表
R25_neck_upper_mount_1_M2_nut | 1 | A2 stainless M2 hex nut AF4 t1.6 | purchase_reference | R23_neck_upper_mount_1_M2_nut | work/r25-bottom-head-entry/mechanics/STEP_毫米/R25_neck_upper_mount_1_M2_nut.step | 几何实例，非新增采购总数；绑带和结头同一物料，导线按独立端号总表
R25_neck_upper_mount_1_M2x18 | 1 | A2-70 socket screw nominal purchase envelope | purchase_reference | R23_neck_upper_mount_1_M2x18 | work/r25-bottom-head-entry/mechanics/STEP_毫米/R25_neck_upper_mount_1_M2x18.step | 几何实例，非新增采购总数；绑带和结头同一物料，导线按独立端号总表
R25_neck_upper_retainer_2_washer | 1 | A2 stainless DIN125 M2.5 washer ID2.7 OD6 t0.5 | manufacturing_candidate | R23_neck_upper_retainer_2_washer | work/r25-bottom-head-entry/mechanics/STEP_毫米/R25_neck_upper_retainer_2_washer.step | 几何实例，非新增采购总数；绑带和结头同一物料，导线按独立端号总表
R25_neck_upper_retainer_2_M2x6 | 1 | A2-70 socket screw nominal purchase envelope | purchase_reference | R23_neck_upper_retainer_2_M2x6 | work/r25-bottom-head-entry/mechanics/STEP_毫米/R25_neck_upper_retainer_2_M2x6.step | 几何实例，非新增采购总数；绑带和结头同一物料，导线按独立端号总表
R25_neck_upper_mount_2_front_washer | 1 | A2 stainless DIN125 M2.5 washer ID2.7 OD6 t0.5 | manufacturing_candidate | R23_neck_upper_mount_2_front_washer | work/r25-bottom-head-entry/mechanics/STEP_毫米/R25_neck_upper_mount_2_front_washer.step | 几何实例，非新增采购总数；绑带和结头同一物料，导线按独立端号总表
R25_neck_upper_mount_2_rear_washer | 1 | A2 stainless DIN125 M2.5 washer ID2.7 OD6 t0.5 | manufacturing_candidate | R23_neck_upper_mount_2_rear_washer | work/r25-bottom-head-entry/mechanics/STEP_毫米/R25_neck_upper_mount_2_rear_washer.step | 几何实例，非新增采购总数；绑带和结头同一物料，导线按独立端号总表
R25_neck_upper_mount_2_M2_nut | 1 | A2 stainless M2 hex nut AF4 t1.6 | purchase_reference | R23_neck_upper_mount_2_M2_nut | work/r25-bottom-head-entry/mechanics/STEP_毫米/R25_neck_upper_mount_2_M2_nut.step | 几何实例，非新增采购总数；绑带和结头同一物料，导线按独立端号总表
R25_neck_upper_mount_2_M2x18 | 1 | A2-70 socket screw nominal purchase envelope | purchase_reference | R23_neck_upper_mount_2_M2x18 | work/r25-bottom-head-entry/mechanics/STEP_毫米/R25_neck_upper_mount_2_M2x18.step | 几何实例，非新增采购总数；绑带和结头同一物料，导线按独立端号总表
R25_neck_upper_P5_PEEK_film | 1 | unfilled PEEK0.25mm formed film | manufacturing_candidate | R23_neck_upper_P5_PEEK_film | work/r25-bottom-head-entry/mechanics/STEP_毫米/R25_neck_upper_P5_PEEK_film.step | 几何实例，非新增采购总数；绑带和结头同一物料，导线按独立端号总表
R25_neck_upper_P5_VMQ_installed | 1 | VMQ50A nominal1.2g/cm3 | manufacturing_candidate | R23_neck_upper_P5_VMQ_installed | work/r25-bottom-head-entry/mechanics/STEP_毫米/R25_neck_upper_P5_VMQ_installed.step | 几何实例，非新增采购总数；绑带和结头同一物料，导线按独立端号总表
R25_neck_upper_P6_PEEK_film | 1 | unfilled PEEK0.25mm formed film | manufacturing_candidate | R23_neck_upper_P6_PEEK_film | work/r25-bottom-head-entry/mechanics/STEP_毫米/R25_neck_upper_P6_PEEK_film.step | 几何实例，非新增采购总数；绑带和结头同一物料，导线按独立端号总表
R25_neck_upper_P6_VMQ_installed | 1 | VMQ50A nominal1.2g/cm3 | manufacturing_candidate | R23_neck_upper_P6_VMQ_installed | work/r25-bottom-head-entry/mechanics/STEP_毫米/R25_neck_upper_P6_VMQ_installed.step | 几何实例，非新增采购总数；绑带和结头同一物料，导线按独立端号总表
R25_neck_upper_power_pair_band_1 | 1 | Daburn2049-A TypeIII PTFE max envelope | lacing_reference | R23_neck_upper_power_pair_band_1 | work/r25-bottom-head-entry/mechanics/STEP_毫米/R25_neck_upper_power_pair_band_1.step | 几何实例，非新增采购总数；绑带和结头同一物料，导线按独立端号总表
R25_neck_upper_power_pair_knot_1 | 1 | Same lacing knot budget | knot_budget | R23_neck_upper_power_pair_knot_1 | work/r25-bottom-head-entry/mechanics/STEP_毫米/R25_neck_upper_power_pair_knot_1.step | 几何实例，非新增采购总数；绑带和结头同一物料，导线按独立端号总表
R25_neck_upper_power_pair_band_2 | 1 | Daburn2049-A TypeIII PTFE max envelope | lacing_reference | R23_neck_upper_power_pair_band_2 | work/r25-bottom-head-entry/mechanics/STEP_毫米/R25_neck_upper_power_pair_band_2.step | 几何实例，非新增采购总数；绑带和结头同一物料，导线按独立端号总表
R25_neck_upper_power_pair_knot_2 | 1 | Same lacing knot budget | knot_budget | R23_neck_upper_power_pair_knot_2 | work/r25-bottom-head-entry/mechanics/STEP_毫米/R25_neck_upper_power_pair_knot_2.step | 几何实例，非新增采购总数；绑带和结头同一物料，导线按独立端号总表
R25_neck_upper_6061_bottom_bridge | 1 | 6061-T651 machined billet | manufacturing_candidate | R23_neck_upper_6061_with_power_pair | work/r25-bottom-head-entry/mechanics/STEP_毫米/R25_neck_upper_6061_bottom_bridge.step | 几何实例，非新增采购总数；绑带和结头同一物料，导线按独立端号总表
R25_top_head_shell_closed_side | 1 | PA2200 PA12 SLS | printed_bottom_entry | R24_top_head_shell_front_cover_lugs | work/r25-bottom-head-entry/mechanics/R25_top_head_shell_closed_side.3mf | 几何实例，非新增采购总数；绑带和结头同一物料，导线按独立端号总表
R25_lower_head_shell_bottom_entry | 1 | PA2200 PA12 SLS | printed_bottom_entry | R12_lower_head_shell | work/r25-bottom-head-entry/mechanics/R25_lower_head_shell_bottom_entry.3mf | 几何实例，非新增采购总数；绑带和结头同一物料，导线按独立端号总表

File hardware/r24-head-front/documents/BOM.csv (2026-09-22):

item | quantity | material/spec | source | status
R24_Microduck_front_face_camera_carrier | 1 | PA2200 PA12 SLS, density scenario | work/r24-head-front/geometry/R24_Microduck_front_face_camera_carrier.3mf | Design candidate; SLS PA12, unit mm
R24_black_camera_eye_bezel | 1 | Black PA2200 PA12 SLS, density scenario | work/r24-head-front/geometry/R24_black_camera_eye_bezel.3mf | Design candidate; SLS PA12, unit mm
R24_top_head_shell_front_cover_lugs | 1 | PA2200 PA12 SLS, density scenario | work/r24-head-front/geometry/R24_top_head_shell_front_cover_lugs.3mf | Design candidate; SLS PA12, unit mm
OS05A10 5MP USB Camera(A),SKU33123 | 1 | Existing camera;25x25mm,21mm pitch,4xD2;D14 lens;USB SH1.0 lead pending | Dimensional purchasing acceptance envelope | Vendor drawing and first article required
M2x10 screw | 4 | HeadD3.8H2,hex1.5 | Dimensional purchasing acceptance envelope | Vendor drawing and first article required
M2x8 screw | 4 | HeadD3.8H2,hex1.5 | Dimensional purchasing acceptance envelope | Vendor drawing and first article required
M2 hex nut | 8 | AF4,H1.6 | Dimensional purchasing acceptance envelope | Vendor drawing and first article required
M2 washer | 4 | OD5,ID2.2,H0.3 | Dimensional purchasing acceptance envelope | Vendor drawing and first article required
M1.6x14 screw | 4 | HeadD3,H1.6,hex1.5 envelope;match actual vendor | Dimensional purchasing acceptance envelope | Vendor drawing and first article required
M1.6 hex nut | 4 | AF3.2,H1.3 | Dimensional purchasing acceptance envelope | Vendor drawing and first article required
M1.6 washer | 4 | OD4,ID1.8,H0.3 | Dimensional purchasing acceptance envelope | Vendor drawing and first article required

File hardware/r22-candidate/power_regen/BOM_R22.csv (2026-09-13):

reference | value | MPN | footprint | side | x_mm | y_mm | rotation_deg | included_part | source_domain | source_ref
C1 | 680uF 25V 20% | EEUFR1E681 | Capacitor_THT:CP_Radial_D10.0mm_P5.00mm | F | 18.0 | 52.0 | 0.0 | True | power | C1
C2 | 680uF 25V 20% | EEUFR1E681 | Capacitor_THT:CP_Radial_D10.0mm_P5.00mm | F | 47.0 | 10.0 | 0.0 | True | power | C2
C3 | 680uF 25V 20% | EEUFR1E681 | Capacitor_THT:CP_Radial_D10.0mm_P5.00mm | F | 47.0 | 23.0 | 0.0 | True | power | C3
C4 | 100nF | GRM188R71H104KA93D | Capacitor_SMD:C_0603_1608Metric | B | 27.0 | 35.0 | 180.0 | True | power | C4
C5 | 100nF | GRM188R71H104KA93D | Capacitor_SMD:C_0603_1608Metric | B | 41.0 | 34.0 | 180.0 | True | power | C5
C6 | 100nF | GRM188R71H104KA93D | Capacitor_SMD:C_0603_1608Metric | B | 41.0 | 36.0 | 180.0 | True | power | C6
C7 | 100nF | GRM188R71H104KA93D | Capacitor_SMD:C_0603_1608Metric | B | 46.0 | 44.0 | 180.0 | True | power | C7
C8 | 100nF | GRM188R71H104KA93D | Capacitor_SMD:C_0603_1608Metric | B | 60.0 | 39.0 | 180.0 | True | power | C8
C9 | 100nF | GRM188R71H104KA93D | Capacitor_SMD:C_0603_1608Metric | B | 26.0 | 50.0 | 180.0 | True | power | C9
C10 | 100nF | GRM188R71H104KA93D | Capacitor_SMD:C_0603_1608Metric | B | 33.0 | 48.0 | 180.0 | True | power | C10
C11 | 100nF | GRM188R71H104KA93D | Capacitor_SMD:C_0603_1608Metric | B | 57.0 | 26.5 | 180.0 | True | power | C11
C12 | 100nF | GRM188R71H104KA93D | Capacitor_SMD:C_0603_1608Metric | B | 9.0 | 20.0 | 180.0 | True | power | C12
C13 | 10uF 50V | GRM32ER71H106KA12L | Capacitor_SMD:C_1210_3225Metric | B | 13.0 | 19.0 | 180.0 | True | power | C13
C14 | 10uF 50V | GRM32ER71H106KA12L | Capacitor_SMD:C_1210_3225Metric | B | 20.0 | 19.0 | 180.0 | True | power | C14
C15 | 100nF | GRM188R71H104KA93D | Capacitor_SMD:C_0603_1608Metric | B | 36.0 | 14.0 | 180.0 | True | power | C15
C16 | 10uF 50V | GRM32ER71H106KA12L | Capacitor_SMD:C_1210_3225Metric | B | 13.0 | 23.0 | 180.0 | True | power | C16
C17 | 10uF 50V | GRM32ER71H106KA12L | Capacitor_SMD:C_1210_3225Metric | B | 20.0 | 23.0 | 180.0 | True | power | C17
C18 | 10uF 50V | GRM32ER71H106KA12L | Capacitor_SMD:C_1210_3225Metric | B | 13.0 | 27.0 | 180.0 | True | power | C18
C19 | 10uF 50V | GRM32ER71H106KA12L | Capacitor_SMD:C_1210_3225Metric | B | 20.0 | 27.0 | 180.0 | True | power | C19
C101 | 2200uF 16V LOW ESR | EEUFR1C222 | Microduck_R22:CP_EEUFR1C222_Horizontal_Clip | F | 1.8 | -6.0 | 0.0 | True | regen | C1
C102 | 100nF | GRM188R71H104KA93D | Capacitor_SMD:C_0603_1608Metric | B | 8.0 | 4.0 | 180.0 | True | regen | C2
C103 | 100nF | GRM188R71H104KA93D | Capacitor_SMD:C_0603_1608Metric | B | 7.0 | 10.0 | 180.0 | True | regen | C3
C104 | 100nF | GRM188R71H104KA93D | Capacitor_SMD:C_0603_1608Metric | B | 16.5 | 8.0 | 180.0 | True | regen | C4
C105 | 100nF | GRM188R71H104KA93D | Capacitor_SMD:C_0603_1608Metric | B | 43.0 | 5.0 | 90.0 | True | regen | C5
C106 | 1uF 10V | GRM188R71A105KA61D | Capacitor_SMD:C_0603_1608Metric | B | 35.7 | 2.0 | 90.0 | True | regen | C6
C107 | 100nF | GRM188R71H104KA93D | Capacitor_SMD:C_0603_1608Metric | B | 35.7 | -3.5 | 90.0 | True | regen | C7
C108 | 100nF | GRM188R71H104KA93D | Capacitor_SMD:C_0603_1608Metric | B | 17.5 | 4.0 | 180.0 | True | regen | C8
C109 | 100nF | GRM188R71H104KA93D | Capacitor_SMD:C_0603_1608Metric | B | 21.0 | 4.0 | 180.0 | True | regen | C9
C110 | 22uF 25V X7R | GRM32ER71E226KE15L | Capacitor_SMD:C_1210_3225Metric | F | 2.8 | 10.0 | 0.0 | True | regen | C10
C111 | 22uF 25V X7R | GRM32ER71E226KE15L | Capacitor_SMD:C_1210_3225Metric | F | 2.8 | 18.0 | 0.0 | True | regen | C11
C112 | 22uF 25V X7R | GRM32ER71E226KE15L | Capacitor_SMD:C_1210_3225Metric | F | 2.8 | 36.0 | 0.0 | True | regen | C12
H1 | M2 NPTH | NO PART | MountingHole:MountingHole_2.2mm_M2 | F | 3.0 | 3.0 | 0.0 | False | power | H1
H2 | M2 NPTH | NO PART | MountingHole:MountingHole_2.2mm_M2 | F | 62.0 | 3.0 | 0.0 | False | power | H2
H3 | M2 NPTH | NO PART | MountingHole:MountingHole_2.2mm_M2 | F | 3.0 | 57.0 | 0.0 | False | power | H3
H4 | M2 NPTH | NO PART | MountingHole:MountingHole_2.2mm_M2 | F | 62.0 | 57.0 | 0.0 | False | power | H4
J1 | CONTROL 3.3V / RUN DEFAULT OFF | BM08B-SRSS-TB(LF)(SN) | Connector_JST:JST_SH_BM08B-SRSS-TB_1x08-1MP_P1.00mm_Vertical | F | 60.0 | 20.0 | 90.0 | True | power | J1
P101 | GND | SOLDER AWG28 PIGTAIL | Microduck_Brake_R8:WireSignal_0p5mm | F | 35.6 | -8.5 | 0.0 | True | regen | P1
P102 | +3V3 | SOLDER AWG28 PIGTAIL | Microduck_Brake_R8:WireSignal_0p5mm | F | 36.87 | -8.5 | 0.0 | True | regen | P2
P103 | I2C_SDA | SOLDER AWG28 PIGTAIL | Microduck_Brake_R8:WireSignal_0p5mm | F | 38.14 | -8.5 | 0.0 | True | regen | P3
P104 | I2C_SCL | SOLDER AWG28 PIGTAIL | Microduck_Brake_R8:WireSignal_0p5mm | F | 39.41 | -8.5 | 0.0 | True | regen | P4
P105 | BRAKE_ACTIVE_N | SOLDER AWG28 PIGTAIL | Microduck_Brake_R8:WireSignal_0p5mm | F | 40.68 | -8.5 | 0.0 | True | regen | P5
Q1 | 60V 2.2mOhm @10V | CSD18540Q5B | Microduck_Power_R8:CSD18540Q5B_DNK | F | 46.0 | 35.0 | 180.0 | True | power | Q1
Q2 | 60V 2.2mOhm @10V | CSD18540Q5B | Microduck_Power_R8:CSD18540Q5B_DNK | F | 57.0 | 35.0 | 0.0 | True | power | Q2
Q3 | TDK enable sink | BSS138 | Package_TO_SOT_SMD:SOT-23 | B | 6.0 | 28.0 | 180.0 | True | power | Q3
Q101 | 60V BRAKE MOSFET | CSD18540Q5B | Microduck_Brake_R8:CSD18540Q5B_DNK | F | 43.0 | -3.5 | 180.0 | True | regen | Q1
Q102 | OPEN DRAIN BRAKE STATUS | BSS138 | Package_TO_SOT_SMD:SOT-23 | B | 20.0 | 7.0 | 180.0 | True | regen | Q2
R1 | 2.45k 0.1% | RT0603BRD072K45L | Resistor_SMD:R_0603_1608Metric | B | 39.0 | 24.0 | 90.0 | True | power | R1
R2 | 17.4k 0.1% | RT0603BRD0717K4L | Resistor_SMD:R_0603_1608Metric | B | 39.0 | 29.0 | 90.0 | True | power | R2
R3 | 1k | ERJ-3EKF1001V | Resistor_SMD:R_0603_1608Metric | B | 24.0 | 35.0 | 180.0 | True | power | R3
R4 | 8.38k 0.1% | RT0603BRD078K38L | Resistor_SMD:R_0603_1608Metric | B | 42.0 | 29.0 | 90.0 | True | power | R4
R5 | 1k 0.1% | RT0603BRD071KL | Resistor_SMD:R_0603_1608Metric | B | 42.0 | 25.0 | 90.0 | True | power | R5
R6 | 1.2k | ERJ-3EKF1201V | Resistor_SMD:R_0603_1608Metric | B | 32.0 | 41.0 | 180.0 | True | power | R6
R7 | 100k | ERJ-3EKF1003V | Resistor_SMD:R_0603_1608Metric | B | 35.0 | 38.0 | 90.0 | True | power | R7
R8 | 100k | ERJ-3EKF1003V | Resistor_SMD:R_0603_1608Metric | B | 29.0 | 38.0 | 90.0 | True | power | R8
R9 | 1.10k 0.1% | RT0603BRD071K1L | Resistor_SMD:R_0603_1608Metric | B | 61.0 | 29.0 | 90.0 | True | power | R9
R10 | 10R 0.1% | RT0603BRD0710RL | Resistor_SMD:R_0603_1608Metric | B | 26.0 | 48.0 | 180.0 | True | power | R10
R11 | 10R 0.1% | RT0603BRD0710RL | Resistor_SMD:R_0603_1608Metric | B | 30.0 | 48.0 | 180.0 | True | power | R11
R101 | 80.6k 0.1% | RT0603BRD0780K6L | Resistor_SMD:R_0603_1608Metric | B | 13.0 | 13.0 | 180.0 | True | regen | R1
R102 | 10.0k 0.1% | RT0603BRD0710KL | Resistor_SMD:R_0603_1608Metric | B | 17.0 | 14.0 | 180.0 | True | regen | R2
R103 | 2.20M 0.1% | RT0603BRD072M2L | Resistor_SMD:R_0603_1608Metric | B | 23.0 | 15.0 | 180.0 | True | regen | R3
R104 | 4.7R | ERJ-3EKF4R7V | Resistor_SMD:R_0603_1608Metric | B | 38.0 | -1.0 | 180.0 | True | regen | R4
R105 | 2.2R | ERJ-3EKF2R2V | Resistor_SMD:R_0603_1608Metric | B | 38.0 | -5.0 | 180.0 | True | regen | R5
R106 | 100k | ERJ-3EKF1003V | Resistor_SMD:R_0603_1608Metric | B | 47.0 | -2.0 | 180.0 | True | regen | R6
R107 | 100k | ERJ-3EKF1003V | Resistor_SMD:R_0603_1608Metric | B | 24.0 | 11.0 | 180.0 | True | regen | R7
R108 | 10R 0.1% | RT0603BRD0710RL | Resistor_SMD:R_0603_1608Metric | B | 22.0 | 0.0 | 180.0 | True | regen | R8
R109 | 10R 0.1% | RT0603BRD0710RL | Resistor_SMD:R_0603_1608Metric | B | 22.0 | -2.5 | 180.0 | True | regen | R9
R110 | 10k | ERJ-3EKF1002V | Resistor_SMD:R_0603_1608Metric | B | 24.0 | 7.0 | 180.0 | True | regen | R10
RS1 | 2mOhm 1% 3W KELVIN | WSL27262L000FEA | Microduck_Power_R8:WSL2726_Kelvin | F | 53.0 | 45.0 | -90.0 | True | power | RS1
RS101 | 2mOhm 1% 3W KELVIN | WSL27262L000FEA | Microduck_Brake_R8:WSL2726_Kelvin | F | 33.0 | -3.5 | 180.0 | True | regen | RS1
U1 | TDK i7C2W020A120V-P03-R | i7C2W020A120V-P03-R | Microduck_Power_R8:TDK_i7C_P03 | F | 8.5 | 16.8 | 0.0 | True | power | U1
U2 | IDEAL DIODE + OV CUT | LM74800QDRRRQ1 | Package_SON:WSON-12-1EP_3x3mm_P0.5mm_EP1.5x2.5mm | B | 44.0 | 40.0 | 180.0 | True | power | U2
U3 | SERVO CURRENT / VBUS 0x41 | INA226AIDGSR | Microduck_R22:TI_DGS0010A_1p45x0p30 | B | 30.0 | 45.0 | 180.0 | True | power | U3
U4 | HARDWARE OC LATCH | INA300AIDGSR | Microduck_R22:TI_DGS0010A_1p45x0p30 | B | 53.0 | 29.0 | 180.0 | True | power | U4
U101 | BUS POWERED 5V LDO | TLV76050DBZR | Package_TO_SOT_SMD:SOT-23 | B | 7.0 | 7.0 | 180.0 | True | regen | U1
U102 | 1.25V PRECISION REF | REF3312AIDBZR | Package_TO_SOT_SMD:SOT-23 | B | 13.0 | 7.0 | 180.0 | True | regen | U2
U103 | REGEN HYSTERETIC COMPARATOR | TLV3201AIDBVR | Package_TO_SOT_SMD:SOT-23-5 | B | 20.0 | 11.0 | 180.0 | True | regen | U3
U104 | GATE SOURCE SINK DRIVER | UCC27511DBVR | Package_TO_SOT_SMD:SOT-23-6 | B | 39.0 | 2.0 | 180.0 | True | regen | U4
U105 | BRAKE CURRENT INA226 0x42 | INA226AIDGSR | Microduck_R22:TI_DGS0010A_1p45x0p30 | B | 26.0 | 4.0 | 180.0 | True | regen | U5
W1 | 4S SWITCHED + | SOLDER AWG16 | Microduck_Power_R8:WirePad_2p4mm_6mm | F | 8.0 | 52.0 | 0.0 | True | power | W1
W2 | GND INPUT | SOLDER AWG16 | Microduck_Power_R8:WirePad_2p4mm_6mm | F | 31.0 | 53.0 | 0.0 | True | power | W2
W3 | SERVO 10.8V | SOLDER AWG16 | Microduck_Power_R8:WirePad_2p4mm_6mm | F | 54.0 | 54.0 | 0.0 | True | power | W3
W4 | GND OUTPUT | SOLDER AWG16 | Microduck_Power_R8:WirePad_2p4mm_6mm | F | 44.0 | 56.0 | 0.0 | True | power | W4
W103 | SERVO_BUS | SOLDER AWG16 | Microduck_Brake_R8:WirePad_2p4mm_6mm | F | 32.0 | -11.5 | 0.0 | True | regen | W3
W104 | RH_LOW | SOLDER AWG16 | Microduck_Brake_R8:WirePad_2p4mm_6mm | F | 44.0 | -11.5 | 0.0 | True | regen | W4

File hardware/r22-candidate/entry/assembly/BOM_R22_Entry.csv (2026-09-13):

reference | value | MPN | footprint | side | x_mm | y_mm | rotation_deg | datasheet
C1 | 100nF | GRM188R71H104KA93D | Capacitor_SMD:C_0603_1608Metric | B | 9.0 | 28.0 | 0.0 | https://www.murata.com/en-global/products/capacitor/mlcc
C10 | 10uF 50V X7R | GRM32ER71H106KA12L | Capacitor_SMD:C_1210_3225Metric | F | 7.0 | 25.5 | 0.0 | https://www.murata.com/en-global/products/capacitor/mlcc
C11 | 100uF 35V | EEUFR1V101 | Capacitor_THT:CP_Radial_D8.0mm_P3.50mm | F | 4.0 | 32.0 | 0.0 | https://industrial.panasonic.com/cdbs/www-data/pdf/RDF0000/ABA0000C1259.pdf
C12 | 22uF 25V X7R | GRM32ER71E226KE15L | Capacitor_SMD:C_1210_3225Metric | F | 13.0 | 35.0 | 0.0 | https://www.murata.com/en-global/products/capacitor/mlcc
C13 | 22uF 25V X7R | GRM32ER71E226KE15L | Capacitor_SMD:C_1210_3225Metric | F | 18.0 | 35.0 | 0.0 | https://www.murata.com/en-global/products/capacitor/mlcc
C14 | 22uF 25V X7R | GRM32ER71E226KE15L | Capacitor_SMD:C_1210_3225Metric | B | 22.0 | 35.0 | 180.0 | https://www.murata.com/en-global/products/capacitor/mlcc
C15 | 22uF 25V X7R | GRM32ER71E226KE15L | Capacitor_SMD:C_1210_3225Metric | B | 28.0 | 35.0 | 180.0 | https://www.murata.com/en-global/products/capacitor/mlcc
C16 | 10uF 10V | GRM21BR71A106KE51L | Capacitor_SMD:C_0805_2012Metric | F | 38.0 | 25.0 | 0.0 | https://www.murata.com/en-global/products/capacitor/mlcc
C17 | 100nF | GRM188R71H104KA93D | Capacitor_SMD:C_0603_1608Metric | F | 33.0 | 30.0 | 0.0 | https://www.murata.com/en-global/products/capacitor/mlcc
C18 | 270uF 10V | EEUFR1A271 | Capacitor_THT:CP_Radial_D6.3mm_P2.50mm | F | 39.0 | 31.0 | 0.0 | https://industrial.panasonic.com/cdbs/www-data/pdf/RDF0000/ABA0000C1259.pdf
C2 | 100nF | GRM188R71H104KA93D | Capacitor_SMD:C_0603_1608Metric | B | 18.0 | 19.0 | 0.0 | https://www.murata.com/en-global/products/capacitor/mlcc
C3 | 100nF | GRM188R71H104KA93D | Capacitor_SMD:C_0603_1608Metric | B | 40.0 | 24.5 | 0.0 | https://www.murata.com/en-global/products/capacitor/mlcc
C4 | 100nF | GRM188R71H104KA93D | Capacitor_SMD:C_0603_1608Metric | B | 40.0 | 27.0 | 0.0 | https://www.murata.com/en-global/products/capacitor/mlcc
C5 | 100nF | GRM188R71H104KA93D | Capacitor_SMD:C_0603_1608Metric | B | 36.0 | 33.0 | 0.0 | https://www.murata.com/en-global/products/capacitor/mlcc
C6 | 100nF | GRM188R71H104KA93D | Capacitor_SMD:C_0603_1608Metric | B | 35.0 | 7.0 | 0.0 | https://www.murata.com/en-global/products/capacitor/mlcc
C7 | 100nF | GRM188R71H104KA93D | Capacitor_SMD:C_0603_1608Metric | B | 45.0 | 10.0 | 0.0 | https://www.murata.com/en-global/products/capacitor/mlcc
C8 | 100pF C0G | GRM1885C1H101JA01D | Capacitor_SMD:C_0603_1608Metric | F | 18.0 | 21.0 | 0.0 | https://www.murata.com/en-global/products/capacitor/mlcc
C9 | 10uF 50V X7R | GRM32ER71H106KA12L | Capacitor_SMD:C_1210_3225Metric | F | 7.0 | 22.0 | 0.0 | https://www.murata.com/en-global/products/capacitor/mlcc
F1 | 2A 125V LOGIC INPUT | 0448002.MR | Microduck_Entry_R8:Fuse_Littelfuse_448 | F | 26.5 | 25.0 | -90.0 | https://www.littelfuse.com/assetdocs/littelfuse_fuse_448_datasheet.pdf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
H1 | M2 NPTH | NO PART | MountingHole:MountingHole_2.2mm_M2 | F | 3.0 | 3.0 | 0.0
H2 | M2 NPTH | NO PART | MountingHole:MountingHole_2.2mm_M2 | F | 23.0 | 3.0 | 0.0
H3 | M2 NPTH | NO PART | MountingHole:MountingHole_2.2mm_M2 | F | 3.0 | 39.0 | 0.0
H4 | M2 NPTH | NO PART | MountingHole:MountingHole_2.2mm_M2 | F | 49.0 | 39.0 | 0.0
J1 | NTC BAT 10k 3977K | SM02B-SRSS-TB(LF)(SN) | Connector_JST:JST_SH_SM02B-SRSS-TB_1x02-1MP_P1.00mm_Horizontal | F | 48.0 | 24.5 | 90.0 | https://www.jst-mfg.com/product/pdf/eng/eSH.pdf
J2 | NTC TDK 10k 3977K | SM02B-SRSS-TB(LF)(SN) | Connector_JST:JST_SH_SM02B-SRSS-TB_1x02-1MP_P1.00mm_Horizontal | F | 48.0 | 31.5 | 90.0 | https://www.jst-mfg.com/product/pdf/eng/eSH.pdf
J3 | NTC BRAKE 10k 3977K | BM02B-SRSS-TB(LF)(SN) | Connector_JST:JST_SH_BM02B-SRSS-TB_1x02-1MP_P1.00mm_Vertical | F | 43.5 | 38.0 | 0.0 | https://www.jst-mfg.com/product/pdf/eng/eSH.pdf
J4 | TO CM4 LOGIC CTRL | SM10B-SRSS-TB(LF)(SN) | Connector_JST:JST_SH_SM10B-SRSS-TB_1x10-1MP_P1.00mm_Horizontal | F | 48.0 | 14.0 | 90.0 | https://www.jst-mfg.com/product/pdf/eng/eSH.pdf
J5 | TO TDK POWER CTRL | BM08B-SRSS-TB(LF)(SN) | Connector_JST:JST_SH_BM08B-SRSS-TB_1x08-1MP_P1.00mm_Vertical | F | 33.4 | 4.0 | 180.0 | https://www.jst-mfg.com/product/pdf/eng/eSH.pdf
J6 | TMP302 THERMAL STOP | BM03B-SRSS-TB(LF)(SN) | Connector_JST:JST_SH_BM03B-SRSS-TB_1x03-1MP_P1.00mm_Vertical | F | 35.5 | 38.0 | 0.0 | https://www.jst-mfg.com/product/pdf/eng/eSH.pdf
J7 | TMP302 THERMAL STOP | BM03B-SRSS-TB(LF)(SN) | Connector_JST:JST_SH_BM03B-SRSS-TB_1x03-1MP_P1.00mm_Vertical | F | 27.5 | 38.0 | 0.0 | https://www.jst-mfg.com/product/pdf/eng/eSH.pdf
J8 | BRAKE INA226 0x42 TELEMETRY | BM05B-SRSS-TB(LF)(SN) | Connector_JST:JST_SH_BM05B-SRSS-TB_1x05-1MP_P1.00mm_Vertical | F | 44.0 | 4.0 | 180.0 | https://www.jst-mfg.com/product/pdf/eng/eSH.pdf
R1 | 10R 0.1% | RT0603BRD0710RL | Resistor_SMD:R_0603_1608Metric | B | 10.0 | 20.0 | 0.0 | https://industrial.panasonic.com/cdbs/www-data/pdf/RDA0000/AOA0000C304.pdf
R10 | 41.0k 0.1% | RT0603BRD0741KL | Resistor_SMD:R_0603_1608Metric | F | 18.0 | 19.0 | 0.0 | https://industrial.panasonic.com/cdbs/www-data/pdf/RDA0000/AOA0000C304.pdf
R11 | 10.0k 0.1% | RT0603BRD0710KL | Resistor_SMD:R_0603_1608Metric | B | 16.0 | 22.0 | 0.0 | https://industrial.panasonic.com/cdbs/www-data/pdf/RDA0000/AOA0000C304.pdf
R12 | 88.7k 0.1% | RT0603BRD0788K7L | Resistor_SMD:R_0603_1608Metric | B | 10.0 | 22.0 | 0.0 | https://industrial.panasonic.com/cdbs/www-data/pdf/RDA0000/AOA0000C304.pdf
R13 | 32.4k 0.1% | RT0603BRD0732K4L | Resistor_SMD:R_0603_1608Metric | B | 32.0 | 31.5 | 0.0 | https://industrial.panasonic.com/cdbs/www-data/pdf/RDA0000/AOA0000C304.pdf
R14 | 10k 0.1% | RT0603BRD0710KL | Resistor_SMD:R_0603_1608Metric | B | 36.0 | 30.0 | 0.0 | https://industrial.panasonic.com/cdbs/www-data/pdf/RDA0000/AOA0000C304.pdf
R2 | 10R 0.1% | RT0603BRD0710RL | Resistor_SMD:R_0603_1608Metric | B | 13.2 | 20.0 | 0.0 | https://industrial.panasonic.com/cdbs/www-data/pdf/RDA0000/AOA0000C304.pdf
R3 | 10k 0.1% | RT0603BRD0710KL | Resistor_SMD:R_0603_1608Metric | B | 30.0 | 8.0 | 0.0 | https://industrial.panasonic.com/cdbs/www-data/pdf/RDA0000/AOA0000C304.pdf
R4 | 10k 0.1% | RT0603BRD0710KL | Resistor_SMD:R_0603_1608Metric | B | 29.5 | 5.0 | 0.0 | https://industrial.panasonic.com/cdbs/www-data/pdf/RDA0000/AOA0000C304.pdf
R5 | 10k 0.1% | RT0603BRD0710KL | Resistor_SMD:R_0603_1608Metric | B | 26.5 | 21.5 | 0.0 | https://industrial.panasonic.com/cdbs/www-data/pdf/RDA0000/AOA0000C304.pdf
R6 | 1k | ERJ-3EKF1001V | Resistor_SMD:R_0603_1608Metric | B | 44.0 | 25.0 | 0.0 | https://industrial.panasonic.com/cdbs/www-data/pdf/RDA0000/AOA0000C304.pdf
R7 | 1k | ERJ-3EKF1001V | Resistor_SMD:R_0603_1608Metric | B | 44.0 | 28.0 | 0.0 | https://industrial.panasonic.com/cdbs/www-data/pdf/RDA0000/AOA0000C304.pdf
R8 | 1k | ERJ-3EKF1001V | Resistor_SMD:R_0603_1608Metric | B | 44.0 | 35.0 | 0.0 | https://industrial.panasonic.com/cdbs/www-data/pdf/RDA0000/AOA0000C304.pdf
R9 | 1k | ERJ-3EKF1001V | Resistor_SMD:R_0603_1608Metric | B | 35.0 | 5.0 | 0.0 | https://industrial.panasonic.com/cdbs/www-data/pdf/RDA0000/AOA0000C304.pdf
RS1 | 2mOhm 1% 3W KELVIN | WSL27262L000FEA | Microduck_Entry_R8:WSL2726_Kelvin | F | 14.0 | 9.0 | 0.0 | https://www.vishay.com/docs/30131/wsl2726.pdf
U1 | BATTERY INA226 0x40 | INA226AIDGSR | Microduck_Entry_R8:TI_DGS0010A_Manufacturer_1p45x0p30 | B | 14.0 | 16.0 | 0.0 | https://www.ti.com/lit/ds/symlink/ina226.pdf
U2 | NTC AND EXCITATION 0x48 | ADS1115IDGSR | Microduck_Entry_R8:TI_DGS0010A_Manufacturer_1p45x0p30 | B | 41.0 | 7.0 | 0.0 | https://www.ti.com/lit/ds/symlink/ads1115.pdf
U3 | 4S to 5.10V 3A MODULE | LMZM33603RLRR | Microduck_Entry_R8:LMZM33603_RLR | F | 16.0 | 27.0 | 0.0 | https://www.ti.com/lit/ds/symlink/lmzm33603.pdf
U4 | BENCH PRIORITY REVERSE BLOCK | TPS2117DRLR | Microduck_Entry_R8:TPS2117_DRL | F | 33.0 | 27.0 | 0.0 | https://www.ti.com/lit/ds/symlink/tps2117.pdf
W1 | BAT_FUSED | SOLDER AWG16 | Microduck_Entry_R8:WirePad_2p4mm_6mm | F | 5.0 | 9.0 | 0.0
W2 | GND | SOLDER AWG16 | Microduck_Entry_R8:WirePad_2p4mm_6mm | F | 5.0 | 16.0 | 0.0
W3 | BAT_MON | SOLDER AWG16 | Microduck_Entry_R8:WirePad_2p4mm_6mm | F | 24.0 | 9.0 | 0.0
W4 | GND | SOLDER AWG16 | Microduck_Entry_R8:WirePad_2p4mm_6mm | F | 24.0 | 17.0 | 0.0
W5 | BENCH_5V | SOLDER AWG20 | Microduck_Entry_R8:WirePad_2p4mm_6mm | F | 32.0 | 13.0 | 0.0
W6 | GND | SOLDER AWG20 | Microduck_Entry_R8:WirePad_2p4mm_6mm | F | 32.0 | 20.0 | 0.0
W7 | SYSTEM_5V | SOLDER AWG20 | Microduck_Entry_R8:WirePad_2p4mm_6mm | F | 40.0 | 13.0 | 0.0
W8 | GND | SOLDER AWG20 | Microduck_Entry_R8:WirePad_2p4mm_6mm | F | 40.0 | 20.0 | 0.0

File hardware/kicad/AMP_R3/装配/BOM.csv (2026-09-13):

Reference | Value | MPN | Quantity | Footprint | Side | Source
U1 | MAX98357AETE+T | MAX98357AETE+T | 1 | Microduck_Audio_R3:MAX98357A_T1633_4 | F | https://www.analog.com/media/en/technical-documentation/data-sheets/MAX98357A-MAX98357B.pdf
J1 | SH8 | SM08B-SRSS-TB(LF)(SN) | 1 | Connector_JST:JST_SH_SM08B-SRSS-TB_1x08-1MP_P1.00mm_Horizontal | F | https://www.jst-mfg.com/product/pdf/eng/eSH.pdf
J2 | 5V INPUT | S2B-PH-K-S(LF)(SN) | 1 | Connector_JST:JST_PH_S2B-PH-K_1x02_P2.00mm_Horizontal | F | https://www.jst-mfg.com/product/pdf/eng/ePH.pdf
F1 | 0.5A 32V FAST | 0467.500NR | 1 | Fuse:Fuse_0603_1608Metric | F | https://www.littelfuse.com/assetdocs/fuse-467-datasheet?assetguid=4a59f034-1cca-460e-a5ba-e1e66247c76d
J3 | SH2 | SM02B-SRSS-TB(LF)(SN) | 1 | Connector_JST:JST_SH_SM02B-SRSS-TB_1x02-1MP_P1.00mm_Horizontal | F | https://www.jst-mfg.com/product/pdf/eng/eSH.pdf
J4 | SH5 | SM05B-SRSS-TB(LF)(SN) | 1 | Connector_JST:JST_SH_SM05B-SRSS-TB_1x05-1MP_P1.00mm_Horizontal | F | https://www.jst-mfg.com/product/pdf/eng/eSH.pdf
R1 | 100k / 15dB | RC0603FR-07100KL | 1 | Resistor_SMD:R_0603_1608Metric | F
R2 | 100k / OFF | RC0603FR-07100KL | 1 | Resistor_SMD:R_0603_1608Metric | F
R3 | 10R 1% 1W | CRCW251210R0FKEG | 1 | Resistor_SMD:R_2512_6332Metric | F
R4 | 10R 1% 1W | CRCW251210R0FKEG | 1 | Resistor_SMD:R_2512_6332Metric | F
C1 | 100nF 16V X7R | GRM188R71C104KA01D | 1 | Capacitor_SMD:C_0603_1608Metric | F
C2 | 10uF 10V X5R | GRM188R61A106KE69D | 1 | Capacitor_SMD:C_0603_1608Metric | F

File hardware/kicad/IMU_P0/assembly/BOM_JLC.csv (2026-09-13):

Comment | Designator | Footprint | Manufacturer | Manufacturer Part Number | Quantity | LCSC Part #
100nF | C1,C2 | Capacitor_SMD:C_0603_1608Metric | YAGEO | CC0603KRX7R9BB104 | 2
2.2uF | C3 | Capacitor_SMD:C_0603_1608Metric | Murata | GRM188R71A225KE15D | 1
4.7k | R1,R2 | Resistor_SMD:R_0603_1608Metric | YAGEO | RC0603FR-074K7L | 2
LSM6DSV16XTR | U1 | Microduck_IMU:LSM6DSV16X_LGA14 | STMicroelectronics | LSM6DSV16XTR | 1 | C5267406
Qwiic_3V3_ONLY | J1 | Connector_JST:JST_SH_SM04B-SRSS-TB_1x04-1MP_P1.00mm_Horizontal | JST | SM04B-SRSS-TB(LF)(SN) | 1

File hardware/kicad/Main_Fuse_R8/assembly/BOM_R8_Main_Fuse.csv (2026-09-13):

reference | MPN | qty | note
F1.H | Keystone3549-2 | 1 | Horizontal MINI holder20A
F1.E | Littelfuse0297015.WXNV | 1 | 15A32VDC fuse; blue
W1/W2 | AWG16 insulated copper solder tails | 2 | Independent clamp;maxbackheight3mm
H1/H2 | M2 insulated mounting hardware | 2 | Hardware from integration CAD

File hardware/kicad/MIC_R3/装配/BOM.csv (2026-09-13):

Reference | Value | MPN | Quantity | Footprint | Side | Source
U1 | T5848 LEFT HQ | MMICT5848-00-012 | 1 | Microduck_Audio_R3:T5848_LGA8_BottomPort | F | https://www.invensense.tdk.com/en-us/download-resource/ds-000479-t5848-datasheet
U2 | TXU0204PWR | TXU0204PWR | 1 | Package_SO:TSSOP-14_4.4x5mm_P0.65mm | F | https://www.ti.com/lit/ds/symlink/txu0204.pdf
U3 | 1.8V LDO | TLV75518PDBVR | 1 | Package_TO_SOT_SMD:SOT-23-5 | B | https://www.ti.com/lit/ds/symlink/tlv755p.pdf
J1 | SH5 | SM05B-SRSS-TB(LF)(SN) | 1 | Connector_JST:JST_SH_SM05B-SRSS-TB_1x05-1MP_P1.00mm_Horizontal | F | https://www.jst-mfg.com/product/pdf/eng/eSH.pdf
C1 | 100nF X7R | GRM188R71C104KA01D | 1 | Capacitor_SMD:C_0603_1608Metric | F
C2 | 1uF 10V X7R | GRM188R71A105KA61D | 1 | Capacitor_SMD:C_0603_1608Metric | B
C3 | 1uF 10V X7R | GRM188R71A105KA61D | 1 | Capacitor_SMD:C_0603_1608Metric | B
C4 | 100nF X7R | GRM188R71C104KA01D | 1 | Capacitor_SMD:C_0603_1608Metric | F
C5 | 100nF X7R | GRM188R71C104KA01D | 1 | Capacitor_SMD:C_0603_1608Metric | F
R1 | 100k SD PULLDOWN | RC0603FR-07100KL | 1 | Resistor_SMD:R_0603_1608Metric | F

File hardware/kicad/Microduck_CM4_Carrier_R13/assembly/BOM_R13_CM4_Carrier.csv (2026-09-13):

reference | value | MPN | footprint | side | x_mm | y_mm | rotation_deg | datasheet
J101 | CM4 J3A 1-100 | DF40C-100DS-0.4V(51) | Microduck_CM4_R8:DF40C_J101 | F | 31.46 | 39.55 | 0 | https://www.hirose.com/product/p/CL0684-4033-4-51
J102 | CM4 J3B 101-200 | DF40C-100DS-0.4V(51) | Microduck_CM4_R8:DF40C_J102 | F | 31.46 | 5.49 | 0 | https://www.hirose.com/product/p/CL0684-4033-4-51
J103 | CM4 J1 1-100 | DF40C-100DS-0.4V(51) | Microduck_CM4_R8:DF40C_J103 | F | 52.980074 | 22.600111 | 0 | https://www.hirose.com/product/p/CL0684-4033-4-51
J1 | SH10 | SM10B-SRSS-TB(LF)(SN) | Connector_JST:JST_SH_SM10B-SRSS-TB_1x10-1MP_P1.00mm_Horizontal | B | 28.0 | 25.0 | 0 | https://www.jst-mfg.com/product/pdf/eng/eSH.pdf
J2 | SH4 | SM04B-SRSS-TB(LF)(SN) | Connector_JST:JST_SH_SM04B-SRSS-TB_1x04-1MP_P1.00mm_Horizontal | B | 14.0 | 26.0 | 180 | https://www.jst-mfg.com/product/pdf/eng/eSH.pdf
J3 | SH8 | SM08B-SRSS-TB(LF)(SN) | Connector_JST:JST_SH_SM08B-SRSS-TB_1x08-1MP_P1.00mm_Horizontal | B | 41.0 | 27.0 | 180 | https://www.jst-mfg.com/product/pdf/eng/eSH.pdf
J4 | SH4 | SM04B-SRSS-TB(LF)(SN) | Connector_JST:JST_SH_SM04B-SRSS-TB_1x04-1MP_P1.00mm_Horizontal | B | 53.5 | 12.0 | 270 | https://www.jst-mfg.com/product/pdf/eng/eSH.pdf
J5 | SH4 | SM04B-SRSS-TB(LF)(SN) | Connector_JST:JST_SH_SM04B-SRSS-TB_1x04-1MP_P1.00mm_Horizontal | B | 53.5 | 21.0 | 270 | https://www.jst-mfg.com/product/pdf/eng/eSH.pdf
J6 | SH4 | SM04B-SRSS-TB(LF)(SN) | Connector_JST:JST_SH_SM04B-SRSS-TB_1x04-1MP_P1.00mm_Horizontal | B | 14.0 | 8.0 | 0 | https://www.jst-mfg.com/product/pdf/eng/eSH.pdf
J7 | SH2 | SM02B-SRSS-TB(LF)(SN) | Connector_JST:JST_SH_SM02B-SRSS-TB_1x02-1MP_P1.00mm_Horizontal | B | 8.0 | 16.0 | 0 | https://www.jst-mfg.com/product/pdf/eng/eSH.pdf
J8 | SH2 | SM02B-SRSS-TB(LF)(SN) | Connector_JST:JST_SH_SM02B-SRSS-TB_1x02-1MP_P1.00mm_Horizontal | B | 24.0 | 12.0 | 0 | https://www.jst-mfg.com/product/pdf/eng/eSH.pdf
W1 | SYSTEM_5V IN | SOLDER AWG20 | Microduck_CM4_R8:Wire_SMD4 | B | 36.0 | 9.0 | 0
W2 | SYSTEM GND | SOLDER AWG20 | Microduck_CM4_R8:Wire_SMD4 | B | 42.0 | 9.0 | 0
U1 | CORE 1.439A EFUSE | TPS259530DSGR | Package_SON:Texas_DSG0008A_WSON-8-1EP_2x2mm_P0.5mm_EP0.9x1.6mm | B | 32.0 | 15.0 | 0 | https://www.ti.com/lit/ds/symlink/tps2595.pdf
R1 | 1.43k 0.1% | RT0603BRD071K43L | Resistor_SMD:R_0603_1608Metric | B | 27.0 | 16.5 | 0
C1 | 4.7nF C0G | GRM1885C1H472JA01D | Capacitor_SMD:C_0603_1608Metric | B | 32.0 | 12.0 | 0
C2 | 10uF 10V | GRM21BR71A106KE51L | Capacitor_SMD:C_0805_2012Metric | B | 36.0 | 15.0 | 0
C3 | 10uF 10V | GRM21BR71A106KE51L | Capacitor_SMD:C_0805_2012Metric | B | 36.0 | 19.0 | 0
C4 | 100nF | GRM188R71H104KA93D | Capacitor_SMD:C_0603_1608Metric | B | 32.0 | 18.0 | 0
R2 | 100k | ERJ-3EKF1003V | Resistor_SMD:R_0603_1608Metric | B | 20.0 | 20.0 | 0
R3 | 100k | ERJ-3EKF1003V | Resistor_SMD:R_0603_1608Metric | B | 40.0 | 20.35 | 0
R7 | 10k 1% | ERJ-3EKF1002V | Resistor_SMD:R_0603_1608Metric | B | 12.6 | 20.0 | 0
R8 | 20k 1% | ERJ-3EKF2002V | Resistor_SMD:R_0603_1608Metric | B | 15.0 | 18.0 | 0
R4 | 22R | ERJ-3EKF22R0V | Resistor_SMD:R_0603_1608Metric | B | 50.0 | 26.0 | 0
R5 | 22R | ERJ-3EKF22R0V | Resistor_SMD:R_0603_1608Metric | B | 50.0 | 28.5 | 0
R6 | 22R | ERJ-3EKF22R0V | Resistor_SMD:R_0603_1608Metric | B | 48.5 | 30.0 | 0
F1 | .25A | 0467.250NRHF | Fuse:Fuse_0603_1608Metric | B | 40.0 | 14.0 | 90 | https://www.littelfuse.com/assetdocs/fuse-467-datasheet?assetguid=4a59f034-1cca-460e-a5ba-e1e66247c76d
F2 | .75A | 0467.750NRHF | Fuse:Fuse_0603_1608Metric | B | 41.5 | 18.0 | 90 | https://www.littelfuse.com/assetdocs/fuse-467-datasheet?assetguid=4a59f034-1cca-460e-a5ba-e1e66247c76d
F3 | .25A | 0467.250NRHF | Fuse:Fuse_0603_1608Metric | B | 8.0 | 11.0 | 90 | https://www.littelfuse.com/assetdocs/fuse-467-datasheet?assetguid=4a59f034-1cca-460e-a5ba-e1e66247c76d
F4 | .5A | 0467.500NRHF | Fuse:Fuse_0603_1608Metric | B | 24.0 | 7.0 | 90 | https://www.littelfuse.com/assetdocs/fuse-467-datasheet?assetguid=4a59f034-1cca-460e-a5ba-e1e66247c76d
U2 | USB2 ESD | USBLC6-2SC6 | Package_TO_SOT_SMD:SOT-23-6 | B | 46.5 | 12.0 | 90 | https://www.st.com/resource/en/datasheet/usblc6-2.pdf
U3 | USB2 ESD | USBLC6-2SC6 | Package_TO_SOT_SMD:SOT-23-6 | B | 46.5 | 21.0 | 90 | https://www.st.com/resource/en/datasheet/usblc6-2.pdf
U4 | USB2 ESD | USBLC6-2SC6 | Package_TO_SOT_SMD:SOT-23-6 | B | 19.0 | 14.0 | 0 | https://www.st.com/resource/en/datasheet/usblc6-2.pdf
TP1 | VBUSDET_TP | TEST ONLY | Microduck_CM4_R8:Test_SMD1 | B | 8.0 | 22.0 | 0
TP2 | OTG_VBUS_ONLY | TEST ONLY | Microduck_CM4_R8:Test_SMD1 | B | 8.0 | 24.0 | 0
TP3 | MASKROM | TEST ONLY | Microduck_CM4_R8:Test_SMD1 | B | 30.0 | 35.0 | 0
TP4 | RESET_N | TEST ONLY | Microduck_CM4_R8:Test_SMD1 | B | 34.0 | 35.0 | 0
TP5 | PWRON_N | TEST ONLY | Microduck_CM4_R8:Test_SMD1 | B | 38.0 | 35.0 | 0
TP6 | GND | TEST ONLY | Microduck_CM4_R8:Test_SMD1 | B | 42.0 | 35.0 | 0
TP7 | CORE_FAULT_N | TEST ONLY | Microduck_CM4_R8:Test_SMD1 | B | 32.0 | 21.0 | 0
TP8 | TDK_IMON | TEST ONLY | Microduck_CM4_R8:Test_SMD1 | B | 24.0 | 21.0 | 0
TP9 | BRAKE_ACTIVE_N | TEST ONLY | Microduck_CM4_R8:Test_SMD1 | B | 28.0 | 21.0 | 0
H1 | M2 NPTH | NO PART | MountingHole:MountingHole_2.7mm_M2.5 | F | 5.0 | 6.0 | 0
H2 | M2 NPTH | NO PART | MountingHole:MountingHole_2.7mm_M2.5 | F | 5.0 | 39.0 | 0
H3 | M2 NPTH | NO PART | MountingHole:MountingHole_2.7mm_M2.5 | F | 52.95 | 5.98 | 0
H4 | M2 NPTH | NO PART | MountingHole:MountingHole_2.7mm_M2.5 | F | 52.95 | 38.98 | 0

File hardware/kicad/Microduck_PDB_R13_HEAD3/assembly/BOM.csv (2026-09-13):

Reference | Quantity | MPN | Value | Footprint | Mounting | Scope | Datasheet
J1 | 1 | S3B-EH(LF)(SN) | PORT 1 | Connector_JST:JST_EH_S3B-EH_1x03_P2.50mm_Horizontal | THT | one PCB; matching housings/terminals in harness BOM | https://www.jst-mfg.com/product/pdf/eng/eEH.pdf
F1 | 1 | 0448003.MR | 3A VERY FAST | Microduck_PDB_R13:Fuse_Littelfuse_448 | SMT | one PCB; matching housings/terminals in harness BOM | https://www.littelfuse.com/assetdocs/littelfuse_fuse_448_datasheet.pdf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
J2 | 1 | S3B-EH(LF)(SN) | PORT 2 | Connector_JST:JST_EH_S3B-EH_1x03_P2.50mm_Horizontal | THT | one PCB; matching housings/terminals in harness BOM | https://www.jst-mfg.com/product/pdf/eng/eEH.pdf
F2 | 1 | 0448003.MR | 3A VERY FAST | Microduck_PDB_R13:Fuse_Littelfuse_448 | SMT | one PCB; matching housings/terminals in harness BOM | https://www.littelfuse.com/assetdocs/littelfuse_fuse_448_datasheet.pdf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
J3 | 1 | S3B-EH(LF)(SN) | PORT 3 | Connector_JST:JST_EH_S3B-EH_1x03_P2.50mm_Horizontal | THT | one PCB; matching housings/terminals in harness BOM | https://www.jst-mfg.com/product/pdf/eng/eEH.pdf
F3 | 1 | 0448003.MR | 3A VERY FAST | Microduck_PDB_R13:Fuse_Littelfuse_448 | SMT | one PCB; matching housings/terminals in harness BOM | https://www.littelfuse.com/assetdocs/littelfuse_fuse_448_datasheet.pdf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
J6 | 1 | SM04B-SRSS-TB(LF)(SN) | GND/DATA IN-OUT | Connector_JST:JST_SH_SM04B-SRSS-TB_1x04-1MP_P1.00mm_Horizontal | SMT | one PCB; matching housings/terminals in harness BOM | https://www.jst-mfg.com/product/pdf/eng/eSH.pdf

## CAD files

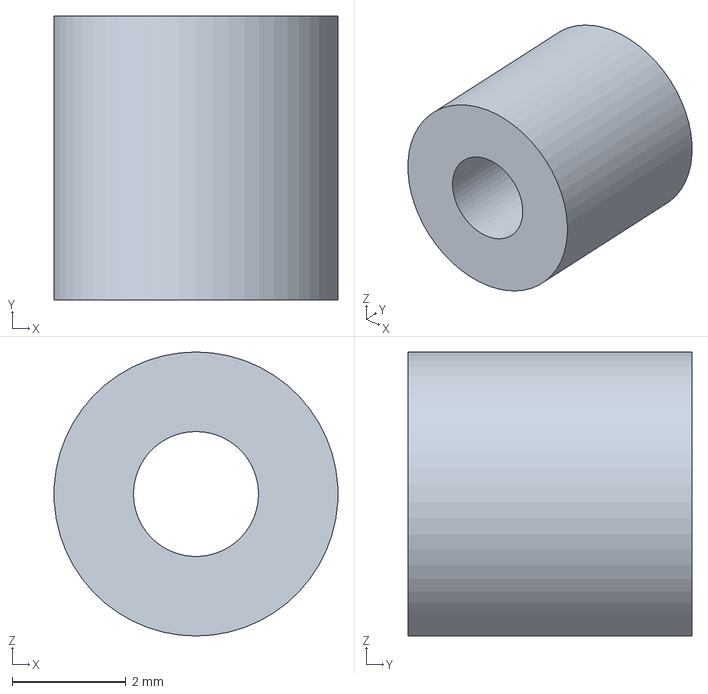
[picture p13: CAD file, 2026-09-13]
hardware/r22-candidate/mechanics/entry_mount/STEP_毫米/R22_Entry_H4_PEEK_5mm.step
4.99 x 5.00 x 5.00 mm

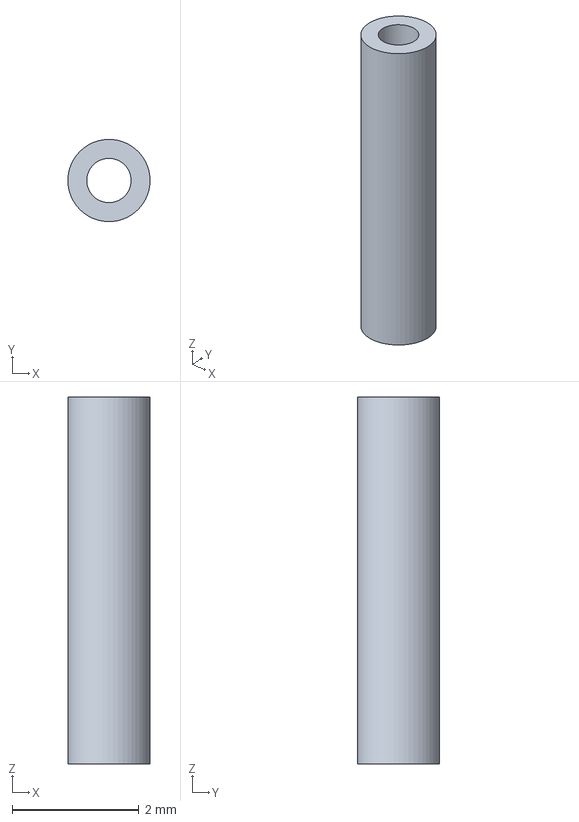
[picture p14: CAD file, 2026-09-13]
hardware/r22-candidate/mechanics/insulation_v2/STEP_毫米/R22_Power_C101_2_INSULATION.step
1.30 x 1.30 x 5.80 mm

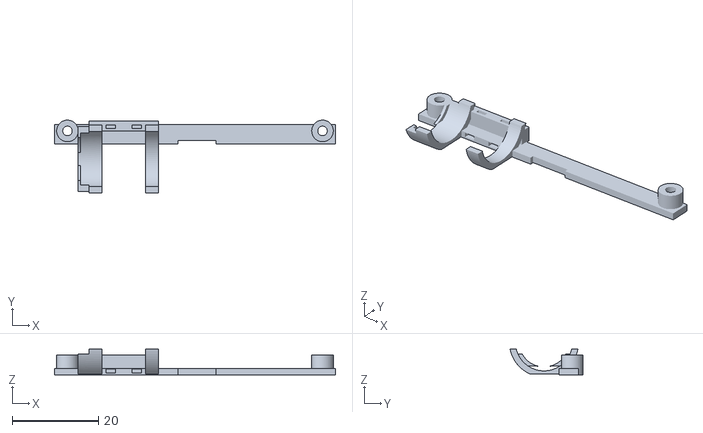
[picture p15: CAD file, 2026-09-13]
hardware/r22-candidate/mechanics/power_cap_mount/STL_装配坐标_毫米/R22_C101_PEEK_front_beam_cradle.stl
65.0 x 16.8 x 5.90

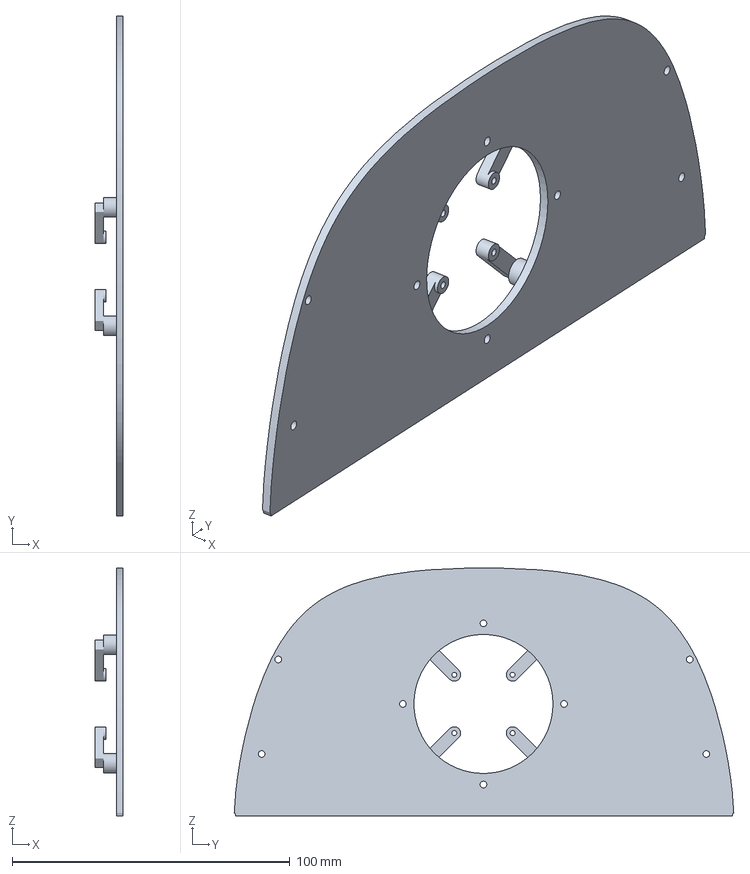
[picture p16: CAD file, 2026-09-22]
hardware/r24-head-front/print/front-face-camera-carrier.3mf
10.0 x 179.7 x 89.2 mm

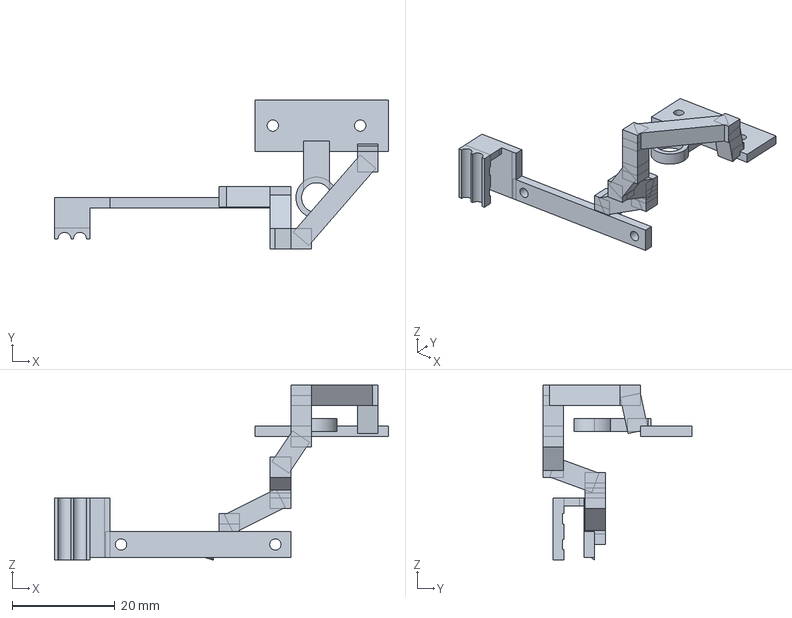
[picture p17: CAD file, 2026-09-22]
hardware/r25-bottom-head-entry/machining/bottom-entry-bridge.step
65.0 x 29.0 x 34.0 mm

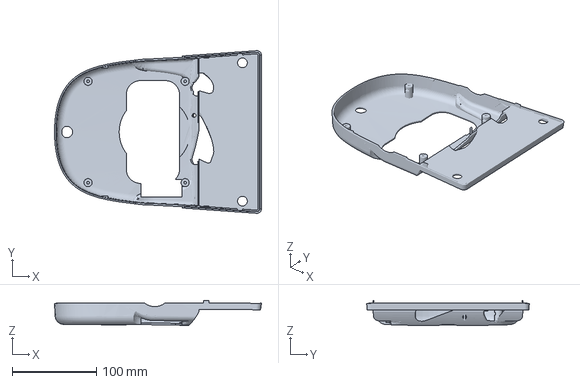
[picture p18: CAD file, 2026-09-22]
hardware/r25-bottom-head-entry/print/R25_lower_head_shell_bottom_entry.3mf
245.1 x 192.6 x 29.6 mm

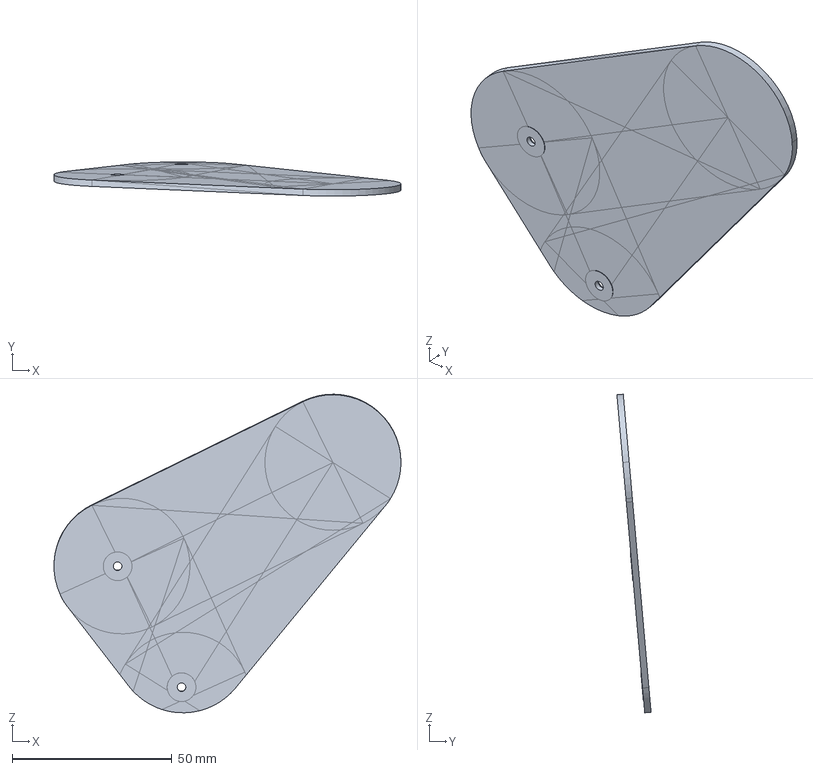
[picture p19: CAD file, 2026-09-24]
hardware/r26-cover-first/step/R26_R_thigh_short_cover.step
108.6 x 10.7 x 99.7 mm

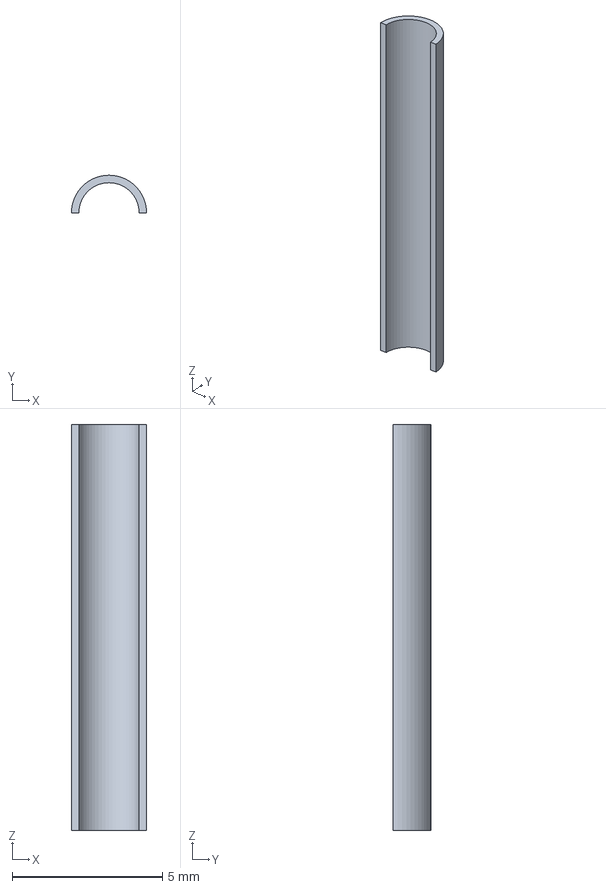
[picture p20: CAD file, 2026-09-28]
hardware/r29-resolution/mechanics/R29_neck_upper_P6_PEEK_exit_lip.step
2.50 x 1.25 x 13.5 mm

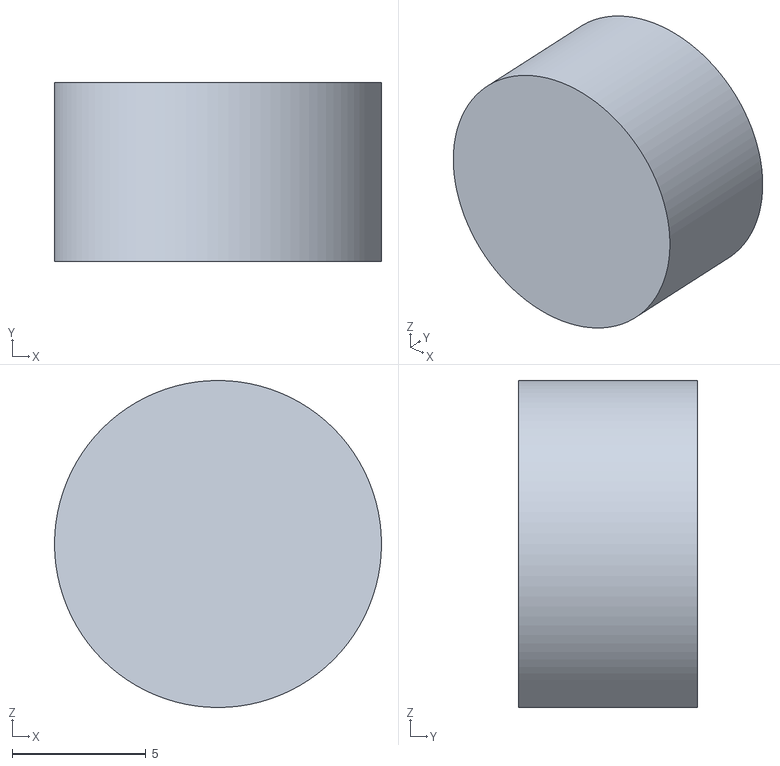
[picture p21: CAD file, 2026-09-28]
hardware/r29-resolution/studies/mouth-counterbalance/spring_body_clearance_envelope.ply
12.2 x 6.70 x 12.2

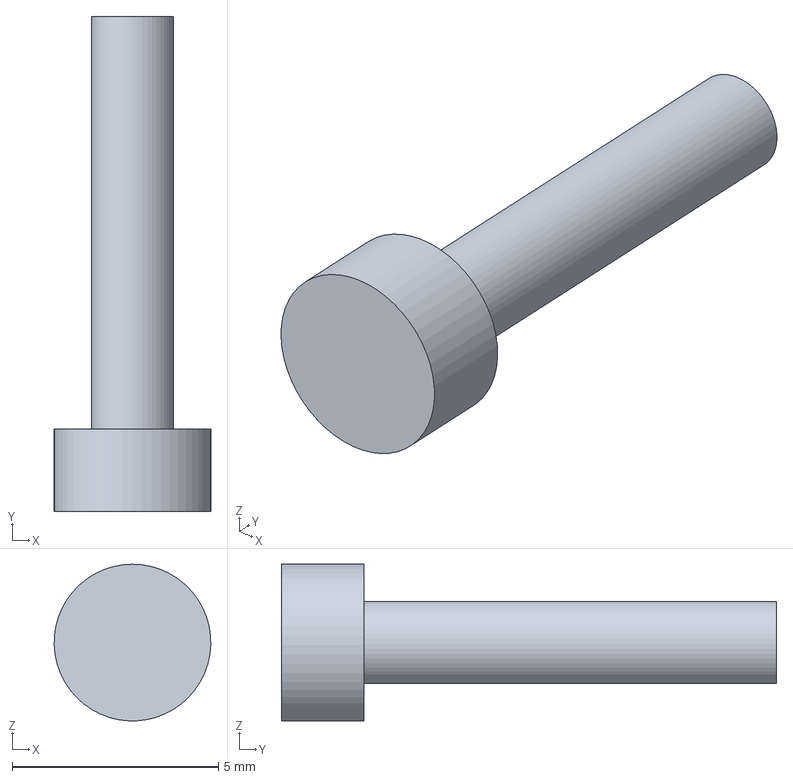
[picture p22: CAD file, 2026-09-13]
hardware/r22-candidate/mechanics/entry_mount/STEP_毫米/R22_Entry_H2_M2x10.step
3.80 x 12.0 x 3.80 mm

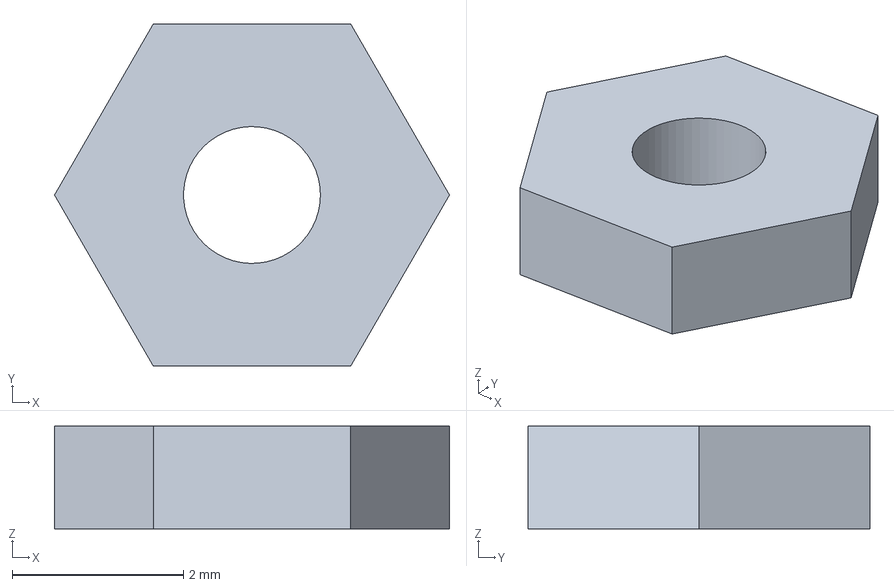
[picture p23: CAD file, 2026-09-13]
hardware/r22-candidate/mechanics/power_cap_mount/STEP_毫米/R22_C101_H2_SHNS_M2_LP.step
4.62 x 4.00 x 1.20 mm

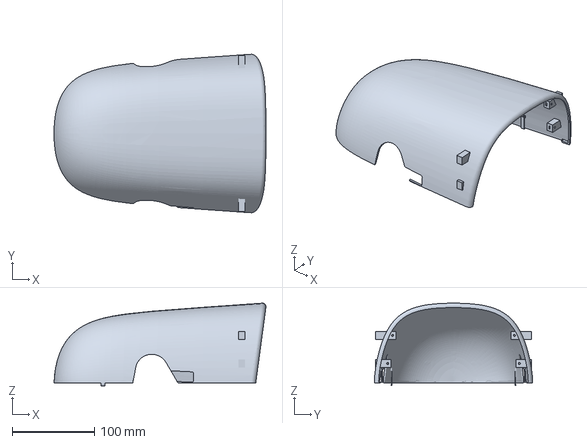
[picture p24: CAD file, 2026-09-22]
hardware/r24-head-front/print/top-head-shell-with-lugs.3mf
257.6 x 192.7 x 100.5 mm

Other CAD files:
hardware/r22-candidate/mechanics/insulation_v2/STL_装配坐标_毫米/R22_Power_C101_2_INSULATION.stl
hardware/r22-candidate/mechanics/insulation_v2/STEP_毫米/R22_Power_C101_1_INSULATION.step
hardware/r22-candidate/mechanics/insulation_v2/STL_装配坐标_毫米/R22_Power_C101_1_INSULATION.stl
hardware/r25-bottom-head-entry/print/R25_top_head_shell_closed_side.3mf
hardware/r26-cover-first/step/R26_L_thigh_short_cover.step
hardware/r22-candidate/mechanics/entry_mount/STEP_毫米/R22_Entry5V_rigid_frame.step
hardware/r22-candidate/mechanics/entry_mount/STEP_毫米/R22_Entry_H1_M2x10.step
hardware/r22-candidate/mechanics/entry_mount/STEP_毫米/R22_Entry_H1_PEEK_5mm.step
hardware/r22-candidate/mechanics/entry_mount/STEP_毫米/R22_Entry_H1_washer.step
hardware/r22-candidate/mechanics/entry_mount/STEP_毫米/R22_Entry_H2_PEEK_5mm.step
hardware/r22-candidate/mechanics/entry_mount/STEP_毫米/R22_Entry_H2_washer.step
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

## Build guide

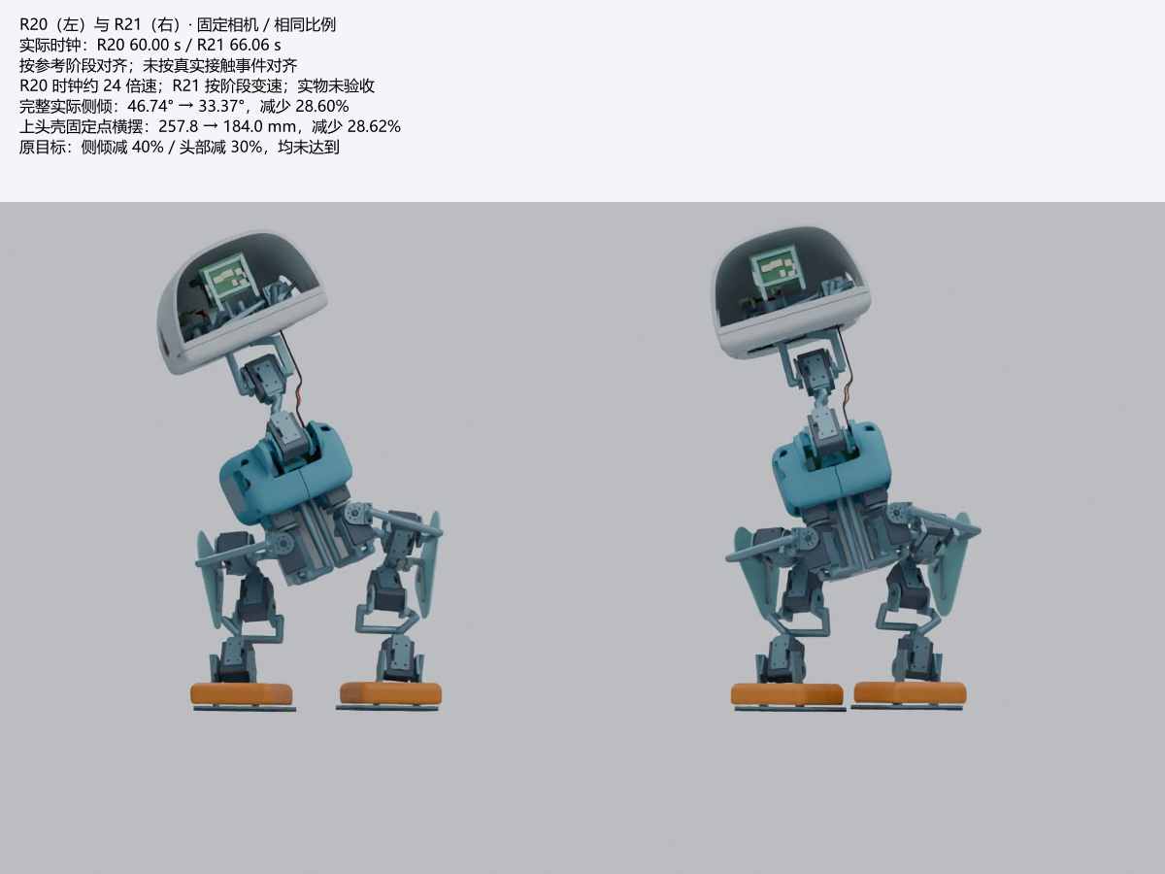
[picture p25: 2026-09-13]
docs/motion-r21/图/同阶段装配对照.png

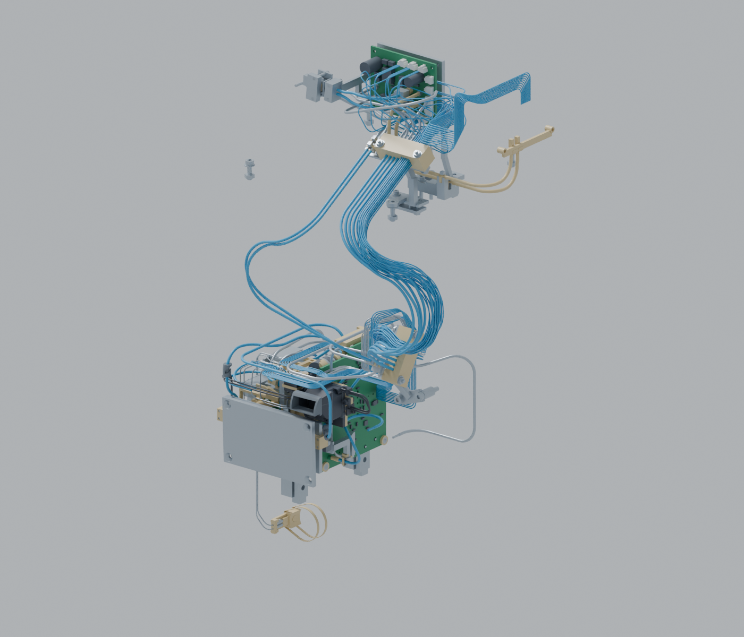
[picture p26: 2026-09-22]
hardware/r23-design/images/03-wiring.png

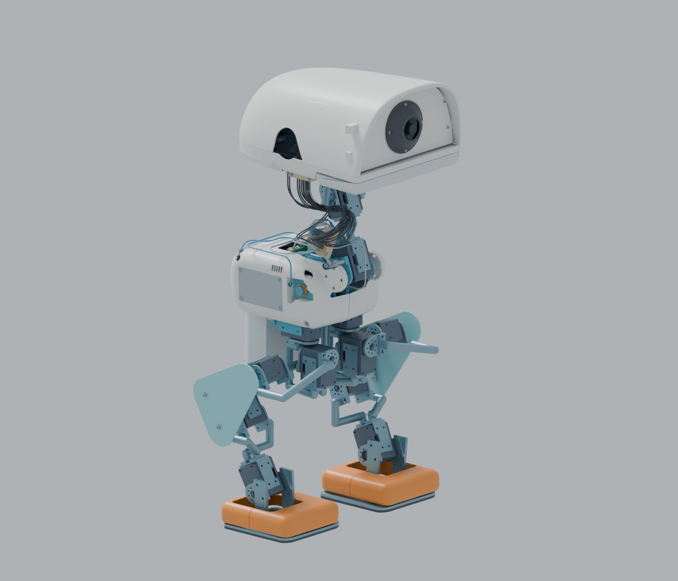
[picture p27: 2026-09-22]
hardware/r25-bottom-head-entry/images/01-complete-assembly.png

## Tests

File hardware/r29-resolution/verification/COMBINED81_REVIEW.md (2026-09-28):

# Final bounded R29 harness feasibility result

All **81 combined endpoint poses** received at least one bounded solve attempt, preserving all 31 R25 conductor identities, free-span lengths, anchor positions and guide tangents. The selected CAD and HOME geometry were not changed.

**59 poses have verified geometric route witnesses; 22 remain unresolved.** “Witness found” means the independent geometry constraints passed; it does not mean a stationary elastic equilibrium was established. The 59 include the nine frozen R25 shapes at their identical coordinates plus 50 newly fitted combined poses. Two initially failed poses were recovered from other nearby successful seeds; a third retry remained unresolved. No further optimization is pending.

For the 59 completed poses:

- 1,829 wire/pose checks passed endpoint identity, tangent/C1 continuity, frozen physical length, minimum R25 radius, wire-pair separation and nonlocal self-clearance checks.
- 111,125 nearby wire/rigid mesh pairs were screened against the frozen R29 selection, including the four new PEEK exit lips: zero intersection volumes above 1e-5 mm³ and zero mesh errors.
- Minimum wire-pair clearance lower bound: **0.0161051404 mm**. This is not manufacturing tolerance allowance.
- Maximum fixed-length residual: **0.00447669038 mm**, below the 0.005 mm numerical acceptance threshold.
- Minimum bare bridge gap: **0.360124458 mm**; no computed bridge gap below the 0.2 mm nominal target. PEEK/VMQ proximity is classified separately and does not establish wear or retention performance.
- Every body report matches its exact route and frozen selection hash. All 1,109 unique retained mesh-file hashes remain unchanged.

`summary.json` contains every pose, result, independent check and source binding. `abrasion_contacts.json` contains all near-contact classifications. `rigid_mesh_hashes.json` binds the full retained geometry. `rerun_manifest.json` binds an exact starting seed and iteration budget for each target. `solver_math_check.json` confirms the normalized bending integral against independent analytic arc integration and a finite-difference gradient check.

The bending objective is a normalized unit-EI integral of curvature squared over a restricted straight/R25-arc basis. It is not a calibrated elastic-rod model: there are no measured bending/torsional stiffnesses, friction, gravity, clamp compliance, force-balance certificate or continuous deformation proof. All 81 targets hold the mouth and other joints at 0 degrees. No manufacturing, physical harness or loaded-walking approval is granted. A bounded failure is not mathematical infeasibility and does not establish that longer wires or changed anchors are required.

## Unresolved target coordinates

Order is neck pitch, head pitch, head yaw, head roll, in degrees.

| Grid index | Target angles |
|---:|---|
| 15 | (-10, 0, 30, -10) |
| 18 | (-10, 15, -30, -10) |
| 19 | (-10, 15, -30, 0) |
| 22 | (-10, 15, 0, 0) |
| 23 | (-10, 15, 0, 10) |
| 24 | (-10, 15, 30, -10) |
| 25 | (-10, 15, 30, 0) |
| 42 | (0, 0, 30, -10) |
| 45 | (0, 15, -30, -10) |
| 46 | (0, 15, -30, 0) |
| 47 | (0, 15, -30, 10) |
| 50 | (0, 15, 0, 10) |
| 51 | (0, 15, 30, -10) |
| 52 | (0, 15, 30, 0) |
| 60 | (10, -15, 30, -10) |
| 69 | (10, 0, 30, -10) |
| 72 | (10, 15, -30, -10) |
| 73 | (10, 15, -30, 0) |
| 75 | (10, 15, 0, -10) |
| 76 | (10, 15, 0, 0) |
| 77 | (10, 15, 0, 10) |
| 78 | (10, 15, 30, -10) |

## Fixed-seed replay

From the repository root, using the recorded Python 3.10 and bundled dependency versions:

```sh
python3.10 work/r29-closure/harness/combined81/reproduce.py --index 0
python3.10 work/r29-closure/harness/combined81/reproduce.py --all
```

The replay verifies input hashes, uses each recorded seed explicitly, and writes to `work/r29-closure/harness/combined81-rerun/`. It never overwrites this evidence or selected CAD. Serial fixed-seed replay avoids the discovery scheduler's completion-order dependence. Bitwise behavior across different numerical libraries or hardware is not claimed; the independent geometric thresholds define acceptance. `evidence_freeze.json` hashes the final artifacts and retained attempt history.

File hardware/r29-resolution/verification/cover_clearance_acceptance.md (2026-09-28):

# R26 右大腿罩—左踝电机间隙与制造验收

## 结论和几何依据

R28 原检查在积分区间 8551–9773 把大段姿态合并估计，得到 0.015113 mm 的正间隙下界；这不是实际接近距离。R29 沿用相同 R26 组件网格、15 关节定义及逐积分步 min/max 盒，对不足目标的区间递归细分。12 张互不重叠的区间证明覆盖全部 9773 个原 R21 积分区间，最小保守刚体间隙下界为 **11.873796 mm**（按 10 mm 目标运行），因此超过 2.2 mm 的名义设计目标。另一轮按 2.2 mm 停止的复算给出 3.586689 mm 下界；两者不矛盾，前者只是细分得更充分。

此项无需改变腿罩或电机位置。基于 10 mm 复核，名义下界对 2.2 mm 目标有 **9.673796 mm** 差额。它只属于该跨腿配对及所记录四步轨迹，不可推导其他 69 组低于 2.2 mm 下界的配对也有同等余量。

## 首件与受载条件

本配对采用如下**设计分配上限**（单侧朝向闭合间隙的最大偏差，包含左右/角度引起的表面位移），不是已测量的制造能力：

| 来源 | 允许最大闭合量 mm | 首件核验 |
|---|---:|---|
| 打印腿罩外表面相对 STEP | 1.0 | 扫描安装基准与朝向左踝电机的最外轮廓 |
| 电机实际外包络相对供应商 CAD | 0.5 | 实物外廓与轴/安装面复测 |
| 腿罩安装堆叠与紧固后姿态 | 1.0 | 装配扫描，含螺钉/垫圈偏心 |
| 左踝电机安装姿态 | 1.0 | 安装面和轴线测量 |
| 关节背隙与规定受载挠曲 | 2.0 | 低电压、峰值姿态和预期负载下量测表面位移 |
| CAD 网格/读回及温度变化 | 0.5 | 对比原生 STEP、实物温度范围包络 |
| **合计** | **6.0** | 各项均须逐项有记录，不能只看总和 |

若全部通过，保守剩余间隙至少 **5.873796 mm**，高于 2.2 mm 目标。任一实测偏差超限或出现未覆盖的新步态时，重新量测和重跑运动区间；不得按本预算制造放行。材料、打印方向、后处理和具体供应商能力尚未确定，表中数值是采购/首件要求，不是厂商已保证的数值。受载与热态尚无样机，**制造及行走的实物验收仍未完成**。

证据：`refine_cover_motor.py`、`cover_motor_10mm_certificate.json`、`cover_motor_target_certificate.json`。输入 SHA256 和逐区间证明随报告保存。

## R29 质量重算轨迹的重新证明

R29 完整装配仅替换下头壳及四片 PEEK 薄膜；右大腿罩、左踝电机的分析网格、安装变换与 15 个关节定义和 R28 输入逐字段一致。R29 估算质量 4.442728968 kg 的最终名义自由底座仿真保存 781,767 个积分步，在 9,773 个连续区间给出全部关节的逐步上下界。用这些**新轨迹区间**重新细分，本配对的 12 张区间证书全部覆盖、无失败，保守名义间隙下界为 **11.722804174 mm**。它低于旧轨迹的 11.873796 mm，故不能用旧轨迹证明代替。

对 R29 实际路径，2.2 mm 设计目标的名义余量为 **9.522804 mm**。若上表全部 6.0 mm 闭合公差/挠度预算经首件实测逐项满足，则最坏剩余间隙至少 **5.722804 mm**；目前这些分配尚未经过供应商与实物确认，不能写成已通过制造间隙。新证书为 `cover_motor_r29_final_10mm_certificate.json`，脚本为 `refine_cover_motor_r29.py`，两者均绑定最终装配与新轨迹的 SHA256。证明范围仍仅为该一对零件及这一条慢速四步轨迹；不是 R29 全部刚体配对、实际受载及所有步态的总证明。

## R29 四个数值工况的同配对复核

对同一装配几何再读回半积分步长、接地摩擦系数 0.5 和九接触点三条 R29 质量重算轨迹，分别取得 **11.669045、11.717192、11.407070 mm** 的保守名义下界；四种工况最低为九接触点的 **11.407070 mm**。各工况均由 12 张无缺口证书覆盖 9,773 个输出区间，半步长工况对应的积分步数另按源文件记录。因此在全部四个**受检慢速数值工况**中，若 6.0 mm 的逐项实物预算都经核验，指定配对最坏剩余下界至少 **5.407070 mm**。不能从这里推出所有步态、所有其它零件对或实际运动均无穿透。

四个证书名为 `cover_motor_r29_final_10mm_certificate.json`、`cover_motor_r29_final_halfdt_10mm_certificate.json`、`cover_motor_r29_final_friction05_10mm_certificate.json`、`cover_motor_r29_final_contact9_10mm_certificate.json`。

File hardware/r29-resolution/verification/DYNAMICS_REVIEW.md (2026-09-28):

# R26 / R29 mass-rebound walking review

**Engineering result: walking acceptance is blocked.** The original four-step gait completes the predeclared *numerical* checks with the R26 and R29 masses only because the simulator permits 0.08 Nm at the mouth joint. The active runtime and structural guard is 0.05 Nm, exceeded throughout all four R29 walks even while the mouth is closed. The 15% assumed leg-motor torque margin also fails. There is no prototype or low-battery sustained-torque qualification.

## Exact configuration

- R26 baseline model: 4.443059766833 kg. R29 selected model: **4.442728967589 kg**, HOME center of mass **[2.925636, −1.627056, 25.124310] mm** in the project assembly frame.
- The R29 shell is `work/r29-mouth-relief/mechanics_10deg/R29_lower_head_shell_mouth_10deg_3mm.ply`, SHA-256 `a498871307dd3cb4fab6493529b748d02d31e2311a8489179fbd15450c0f19e3`. It replaces the R25 lower shell once. The four PEEK exit lips replace four older films once, with net mass **+0.006892 g**. The 31 free head-harness sections remain paired 50/50 rigid mass surrogates, not flexible cables.
- Body inertias are recomputed from the selected mass rows. Five randomized articulated poses give row-summed world COM versus MuJoCo COM errors below **2.3×10⁻¹⁵ m**. Joint pivots, force caps and foot-contact arrays match the frozen original model. Material densities and purchased-component masses remain engineering estimates.
- The selected 0–10° mouth cap is an independent firmware/geometry constraint. This four-step trace holds the mouth close to HOME; it does not test the full mouth movement during walking.

## Four complete final-model runs

The predeclared checks require ≥2 forward steps per foot, ≥15 mm net forward travel per foot, root and joint tracking errors ≤3°, stance-outline slip ≤3 mm, saturation ≤20 ms, and peak swing-sole clearance ≥2 mm. All four cases meet only those frozen numerical thresholds under the inconsistent 0.08 Nm simulated mouth cap. They do **not** pass the active 0.05 Nm mouth structural guard. Each run has a continuously integrated free base and lasts **195.442 s**; this is an extremely slow diagnostic, not a normal walking-speed test.

| R29 case | dt / friction / sole contact | Worst joint torque | Assumed cap use | Loaded foot slip L / R | Body roll peak-to-peak |
| --- | --- | ---: | ---: | ---: | ---: |
| Nominal | 0.25 ms / 0.8 / 4 | left hip roll 0.859552 Nm | 95.51% | 0.940 / 0.646 mm | 33.382° |
| Half timestep | 0.125 ms / 0.8 / 4 | left hip roll 0.835505 Nm | 92.83% | 0.926 / 0.635 mm | 33.383° |
| Low friction | 0.25 ms / 0.5 / 4 | left hip roll 0.859514 Nm | 95.50% | 0.934 / 0.646 mm | 33.382° |
| Contact partition | 0.25 ms / 0.8 / 9 | right hip roll 0.838900 Nm | 93.21% | 0.576 / 0.295 mm | 33.301° |

The R26 mass baseline also passes all four numerical checks. Its worst case is nominal left hip roll **0.859966 Nm**. The R29 nominal change reduces that modeled peak by only **0.000414 Nm**. Body roll remains essentially the R21 result of **33.369°**; this rebind is not a lateral-sway improvement.

The previous 0.9 Nm hip-roll and 1.35 Nm hip-pitch/knee caps are **unmeasured engineering targets**. Across all four R29 cases, measured continuous capacity at the specified low-voltage/temperature/duration would need to be at least **1.011237 Nm left hip roll**, **0.986941 Nm right hip roll**, **1.448551 Nm right knee**, and **1.445806 Nm left hip pitch** to retain 15% peak headroom in this model. The 10.30–10.35 V, 40°C, 7200 s actuator bench test has **not run**. A purchased motor's stall rating does not establish any of these sustained values.

## Active mouth structural guard: hard blocker

The published runtime source `work/openduck-publish/repository/software/r8/rk_runtime/microduck_rk/motion_limits.py` fixes `MOUTH_STRUCTURAL_TORQUE_NM = 0.05`, while the R20/R29 simulation model leaves the mouth-actuator cap at **0.08 Nm**. The simulated mouth peaks for the four final cases are **0.058760, 0.058370, 0.058761, and 0.059250 Nm**; RMS is about **0.056672 Nm** in every case. All **9,774** saved samples in each case exceed 0.05 Nm, despite actual mouth angles staying within about ±0.004° of closed. This is a continuous holding load, not a short gait impulse.

A level-base HOME calculation from the selected model requires **−0.056119 Nm** just to hold the mouth closed; at 10° it still requires **−0.051982 Nm**. The moving mouth assembly is 90.652 g, with its center 63.104 mm forward of the +Y hinge. The revised lower-head shell is on the parent link and therefore does not cause this mouth-axis gravity moment. A passive closing assist would need to offset at least **0.009251 Nm** at the observed worst case merely to meet the hard guard, or **0.016751 Nm** for an 85%-of-guard design target, before manufacturing, spring-rate, position, temperature and motion margins. Those numbers are sizing targets, not an approved spring. The remedy requires a source-bound CAD installation, retained 0–10° clearance, rated torque over angle, and four-case rerun with the **0.05 Nm** active cap. Increasing the software guard is not an authorized shortcut. The direct evidence is `mouth_structural_guard_audit.json`.

## Planned swing contact audit

The acceptance check tests *peak* swing clearance; it does not assert zero contact throughout the named swing interval. The saved 20 ms samples show transient normal loads during lift-off and landing. In all four R29 cases, every >2 N contact sample lies in the first or last 10% of planned swing, while the central 20–80% has zero sampled contact force. The longest nominal loaded transfer run lasts **0.96 s**; the nominal maximum force is **7.592 N** and the sampled normal impulse reaches **7.814 N·s** per planned swing. During such >2 N runs, foot-center motion is at most **0.179 mm** nominal (**0.182 mm** over all cases). Thus the saved trace does not show mid-swing drag, but this is a **post-hoc diagnostic** and does not exclude a brief event between 20 ms samples. A future explicit acceptance criterion could require >2 N contact only in the outer 10% of planned swing and ≤0.5 mm loaded foot-center movement; it must be declared before the next design-validation run.

## Gait changes considered

At R26 mass, 1.3× retiming, a modified double-support load target, and 3 mm/5 mm rightward lateral-COM waypoints were integrated. None reached the 15% assumed-cap margin while retaining the four-step contact checks. The best 5 mm shift still used **93.01%** of the 0.9 Nm hip-roll target. That modified path is **not selected**; the final R29 runs retain the original, already CAD-reviewed gait. A larger motor or further sway retune requires separate CAD, balance, thermal, and battery checks.

## Model-limited balance observation

In all four selected-model runs, saved root height remains about **250.6–259.8 mm** and maximum absolute root tilt is about **18.3°**. After the initialized t=0 sample, every saved frame retains at least one foot with ≥2 N normal load; no numerical fall occurs. These are 20 ms sampled observations, not a support-polygon, capture-point, disturbance-recovery, or physical balance margin. `stability_sample_audit.json` preserves the source-bound values.

## Replay and limits

The nominal CAD replay is `R29_final_nominal/dynamic_trace_for_CAD.json` (SHA-256 `18c88537f29bdc1f58752ca969612dc5b06b51fd656afd9e1129b2e5d231e0c5`). It has 9,774 time-ordered samples with all 15 joint angles and a 4×4 base transform. `R29_final_nominal/interval_joint_bounds.json` encloses joint values at all **781,767 numerical integration endpoints** in 9,773 successive 20 ms intervals; a separate rigid-body CAD collision pass is still required. These bounds do not account for manufacturing tolerances or flexible cable movement.

MuJoCo retains the original R20 foot-contact shape; the changed covers and shell are not its collision bodies. The model omits actuator voltage sag and heat, backlash/compliance, harness bending, real friction variation, falls caused by control latency, and physical endurance. Numerical threshold success must not be marked as manufacturing or walking acceptance, particularly while the active mouth structural guard is violated.

Machine-readable evidence is in `R29_dynamics_validation.json`; transfer contact timing is in `swing_contact_audit.json`. Both bind their input artifacts by SHA-256.

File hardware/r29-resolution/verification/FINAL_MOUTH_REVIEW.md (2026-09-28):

# R29 嘴部与下头壳：10° 运行方案复核

**选定 CAD**：在 R26 装配中以 `R29_lower_head_shell_mouth_10deg_3mm` 替换 `R25_lower_head_shell_bottom_entry`；保持 R12 金属嘴部载体、转轴、头部外形以及四个 M3 安装中心不变。打印制造母版是 `mechanics_10deg/R29_lower_head_shell_mouth_10deg_3mm.3mf`，对应的精确索引分析网格是同目录 `.ply`。安装项补丁见 `assembly_patch_10deg.json`。先前 12°/25° 减料方案仅是对比试验，不能混入选定装配。

## 几何和运动

- R26 原件在张嘴 8.75° 首次出现下头壳与嘴部载体的真实网格体积交集。新的 10° 方案保留一个水密、单连通的 PA12 打印件，移除 363.109 mm³；体积 83,156.252 mm³，估算质量 77.335314 g（原件 77.673005 g）。3MF/PLY 索引、面数、体积和哈希已回读。
- 以 0.25° 间隔对 0–10° 的载体求扫掠体，并用包含半径 3.45 mm 球的 80 面凸体外扩。载体顶点离轴最大 179.6403 mm；任意未采样角度到最近采样角度的位移上界为 0.391915 mm，故**名义刚体网格的连续角度保守间隙下界为 3.0580858 mm**。另以 0.125° 间隔检查 81 个角度：真实穿透 0，3.0 mm 外扩体交集 0。证明只对这组绑定哈希、刚体、关节轴和 0–10° 生效。
- 超限检查采用 0.05° 步长：3.0 mm 间隙条件首次在 10.50° 失败；2.2 mm 条件在 11.30° 失败；真实穿透在 13.55° 首次出现。因此现有软件 12° 上限必须改为 **10° 绝对上限**。25° 不是此方案的允许行程。

## 安装和邻件

- 用 R26 的 1,193 项刚体选择检查装配 HOME，实际落入下头壳包围盒的 116 项均已逐一比较新旧交集；没有新增穿透。四组原有 M3 螺母的微小名义接触未增大。31 项柔性件不属于这项刚体检查。
- 对四个壳体螺钉中心在 z=207–227 mm、半径 4/6/10 mm 的材料做体积比对。变化仅发生于 (+55,+60) mm 位置；其中半径 6 mm 区域从 704.759 降到 669.394 mm³，保留约 95.0%。其余三个安装位在这项指标中不变。
- 对 (+55,+60) mm 安装位在 z=212.5–218.75 mm 每 0.25 mm 取截面。以半径 1.6 mm 孔计，最小径向实体喉宽为 **1.30317 mm**；原 R25 螺母侧槽为 **1.30014 mm**。在 z=213 mm 这处新切口的喉宽是 **2.107 mm**。这是截面几何量，不能代替螺母承压、打印各向异性或疲劳强度试验。整体壳体的最小壁厚也尚未完成独立测量。

## 放行边界

- 3.0580858 mm 名义证明距离 2.2 mm 制造目标只有 **0.8580858 mm** 可用于打印偏差、CNC 偏差、装配定位、弹性变形、温度与角度误差的合计；这些误差还没有来源受控的公差堆栈，因此**不能据此声称 2.2 mm 实物间隙已达标**。首件必须在装配受载后扫查 0–10°、测量最小间隙，做螺母座拉脱/扭矩和寿命试验。
- 当前 R26 选择中未找到经验证的嘴部机械硬止挡。可在固定的 `mouth_candidate_fixed` 与转动的嘴部载体之间另做可调金属限位，但接触位置、工具通道、限位扭矩和全行程避让尚未完成 CAD/实物验证；此文件不把它列为已安装零件。运行时必须执行角度拦截并在首件测定过冲；断电/回驱过转仍需物理措施。
- STL 转换丢失了原索引网格的水密拓扑；三角面缝合 STEP 得到无效 BREP。两者**没有作为制造母版交付**。请使用哈希绑定的 3MF。现阶段 CAD 名义运动通过，不代表结构承载、打印公差或整机实物放行。

证据：`clearance_review_10deg.json`、`mount_review_10deg.json`、`neighbor_review_10deg.json`、`manifest_10deg.json` 和 `assembly_patch_10deg.json`。PLY SHA-256 `a498871307dd3cb4fab6493529b748d02d31e2311a8489179fbd15450c0f19e3`；3MF SHA-256 `761ed66bbcfe119d8b3fe68610e65566040e3f9b8025218c9ff46f53e3751905`。

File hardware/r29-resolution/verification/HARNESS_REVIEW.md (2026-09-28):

# R26 31-wire neck harness: delta audit and release gates

The R26 thigh-cover change does not introduce a new nominal clash with the
31 selected flexible neck wires. It does **not** qualify the harness for
manufacture or walking. The free wires are elastic bodies, while the R26
rigid checker omitted them. This review binds the selected geometry and
separates deliberate insulation/guide contact from uncontrolled pinching.

## Recomputed evidence

- [`audit_r26_flex.py`](audit_r26_flex.py) compares the R26 and R25 selected
  STEP/STL hashes and joint tables. All 31 free wires are identical. It
  rechecks the nine R25 route cases (HOME and the two single-axis endpoints
  of neck pitch ±10°, head pitch ±15°, yaw ±30° and roll ±10°): 17,131
  wire/body near pairs, no reported positive-volume intersection. Those are
  nine distinct mathematically fitted routes, not a continuously deforming
  cable simulation.
- For those nine route shapes, a deliberately oversized analytic envelope
  covering every line, circular arc, and maximum insulation OD has a lowest
  point at **z = 72.142 mm** in the trunk frame. The two R26 thigh covers
  reach no higher than **z = 20.287 mm** over all 9,773 recorded numerical
  walking intervals, using joint-range displacement bounds. Their conditional
  vertical separation is **51.855 mm**, exceeding the 2.2 mm hard-part
  design target. This remains conditional on real wires staying inside the
  modelled envelope; a loose, sagging harness has not been simulated.
- The closest nominal wire pair in the nine poses is **S19/S25, 0.0161 mm**
  at head pitch −15°. Individually insulated wires in a controlled bundle
  may touch, so the value is not itself a metal collision. It cannot serve
  as manufacturing tolerance or proof that loose wires will not rub.

The source hashes, case-by-case numbers and envelope are in
[`r26_flex_audit.json`](r26_flex_audit.json). Guide proximity is separately
recomputed in [`guide_near_clearance.json`](guide_near_clearance.json).

## Pinch/abrasion classification

| Pair family | Smallest nominal mesh gap | Intended function | Release disposition |
|---|---:|---|---|
| Free wire to its own fixed tail | 0 mm at the conductor junction | Continuity of the same lead | Intended mate; inspect insulation transition and strain relief |
| P5/P6 to installed VMQ liner | 0 mm at the guide | Compliant grip | Intended contact; verify compression, retention and insulation condition on first article |
| P5/P6 to PEEK film, upper/lower | 0.110/0.110 mm | Replaceable wear barrier near power-wire exit | Very small as-modelled gap; assembled film coverage and no pinching are unproven |
| Signal wire to upper/lower PEEK comb | 0.161/0.161 mm | Channelled guidance | Intended proximity; channel finish/size and wire OD require as-built measurement |
| P5/P6 to upper/lower 6061 bridge | 0.360/0.360 mm | Structural bridge, **not** a contact surface | No nominal intersection, but metal abrasion margin is too small to inherit production approval |
| Free wire to new R26 thigh covers | ≥51.855 mm conditional vertical bound | No contact intended | R26 cover delta cleared for the modelled route and recorded gait only |

Existing retention hardware is the **upper and lower PEEK comb housings,
VMQ inserts, PEEK retainers, P5/P6 PEEK films and PTFE lacing bands** in the
selected R25/R26 assembly. These parts must remain in the build; removing
one invalidates the clearance and strain-relief argument. The free span is
not yet contained by a common sleeve. A nominal 14 mm common braid cannot
be slipped over the selected HOME layout: at z = 150 mm, one sampled point
per wire already spans **55.161 mm center to center**. See
[`sleeve_feasibility.json`](sleeve_feasibility.json). A compact common sleeve
requires a full route, clip and guide redesign with new CAD/body checks.
Adding individual tubing at the 0.110 mm PEEK-film gap would also consume
the existing nominal space, so it is not a safe drop-in fix.

A local S25 +0.5 mm x adjustment near the S19/S25 gap was tested, not
selected. Although it opened that pair to 0.213 mm, it overlapped S24 and
changed the route length by 0.164 mm; larger shifts violated the 25 mm bend
geometry. [`s25_probe.json`](s25_probe.json) records this failed diagnostic.
The correction must coordinate neighbouring conductors and maintain all
31 endpoint/length/radius constraints.

## Design and first-article gate

Before issuing a manufacturing release, solve all **81 combined endpoint
poses** (three values for each of the four head/neck axes) with the same
31 cut lengths, both clamps, the finished guide/bridge meshes, and the
repaired mouth travel. Validate continuous transitions on the commanded
head and walking trajectories using a cable model with measured bending and
torsional stiffness, self-contact and friction. The nine existing independent
fits cannot be interpolated as a physical cable solution. Model maximum OD,
actual clamp positions and worst measured assembly variation. Resolve any
uncontrolled rigid-metal contact by rerouting or increasing a replaceable
PEEK liner/bridge relief, then rerun the interference check. Do not simply
whitelist a zero-gap pair.

For the first built unit, measure each finished comb slot, PEEK film,
bridge edge and wire maximum OD; deburr all 6061/PEEK edges and photograph
liner coverage. Number-check and measure all 31 conductors against the
selected R25 cut-length table. On a supported, current-limited bench, move neck pitch to
±10°, head pitch to ±15°, yaw to ±30° and roll to ±10°, then exercise
all 81 combined endpoint poses and continuous transitions at the intended
speed. Inspect in situ with a borescope: no wire may touch bare 6061 or a
fastener edge, enter a pinch line or pull taut; the minimum visible metal
separation target is **0.2 mm** at every reachable pose. PEEK/VMQ contact is
allowed only at the intended guide/retainer locations with no extrusion,
cut, flat spot or slippage. Keep the existing **≥25 mm free-wire bend
radius** design requirement unless the actual selected wire datasheet is
more restrictive.

Apply the already specified retention test: **5 N to each conductor,
never more than 5 N total simultaneously**, with **≤0.2 mm slip** and no
insulation damage. Continuously monitor all 31 circuits during motion; a
single open/intermittent event fails. Run an initial 10,000 full-range
head-motion cycles, inspecting guide exits, PEEK film and 6061 witness
points at intervals and afterwards. This is a qualification screen, not a
service-life claim. Record post-cycle continuity, resistance and insulation
condition against pre-cycle measurements. Repeat with the gait playback and
camera/mouth wiring active after the mouth collision is fixed. Any abrasion
or pinch requires a revised physical route or guide and a new CAD audit.

**Current gate:** R26 thigh-cover-to-modelled-wire clearance is closed;
combined-pose cable deformation, guide tolerances and fatigue are open.
No physical harness, manufactured guide measurements or loaded walking test
exists, so this review cannot approve the 31 flexible wires for production.

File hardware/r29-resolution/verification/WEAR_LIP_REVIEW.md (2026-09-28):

# R29 PEEK bridge-exit wear lips: manufacturing candidate

The four P5/P6 power-wire PEEK films have been lengthened **1.5 mm toward
the free span** at both the upper and lower neck guides. This shields the
edge of each 6061 open groove with the same replaceable PEEK material already
selected for the original 12 mm bearing. The 6061 STEP files, attachment
bores, 0.55 mm nominal support web, lacing channels and structural load path
are **unchanged**. Each new STEP contains its old film solid and adds
1.32536 mm³ at the free exit; four films change estimated mass by
**+0.006892 g**.

The section is an open semicircular strip, **inner radius 1.00 mm, outer
radius 1.25 mm, 0.25 mm nominal thickness**. The local carrier coordinate
continues from **T = −1.5 mm to T = 12 mm** instead of 0..12 mm. The
semicircle opens toward positive local V. Cut 13.5 mm long from unfilled
PEEK film, form on the R1.00 mandrel, and deburr the free edge with a
0.05–0.10 mm edge break. Inspect the formed profile and P5/P6 jacket OD.
No adhesive strength is assumed; the selected bands and frictional grip
remain the retention method and require the established 5 N/≤0.2 mm
first-article check. These four replacement films must never be stacked on
their old versions.

[`wear_lip_manifest.json`](wear_lip_manifest.json) identifies the four
replacement CAD solids. Full STEP and installed-coordinate STL live in
[`geometry/`](geometry/). [`r26_selection_patch.json`](r26_selection_patch.json)
is a source-hash-bound four-for-four assembly patch with item names, paths,
hashes, link frames and mass accounting; it has not changed the original
R26 selection in place.

The post-change checks are:

| Screen | Coverage | Result |
|---|---:|---|
| New films vs free wires | 4 × 31 × 9 = 1,116 film/wire/pose pairs; 610 exact native-CAD near checks | No positive-volume intersection; minimum P5-to-film gap 0.111 mm |
| Added lip material vs all other R26 rigid parts | 4 × 1,189 × 9 = 42,804 broad pairs; 260 near, including 20 triangulated shell pairs | No positive-volume intersection and no unresolved pairs |
| Rigid near-contact classification | 108 fixed conductors, 22 lacing, 74 PEEK/VMQ guides, 20 printed shells, 36 unchanged 6061 bridges | All added-lip intersections zero |
| 81 combined endpoint poses, 31 wires | 2,511 straight endpoint-length necessary conditions | All pass; worst extra length over chord is 78.673 mm for P6 at (+10,+15,−30,+10)° |

Evidence: [`wear_lip_wire_screen.json`](wear_lip_wire_screen.json),
[`wear_lip_rigid_delta_screen.json`](wear_lip_rigid_delta_screen.json),
[`wear_lip_contact_review.json`](wear_lip_contact_review.json), and
[`anchor81_length_screen.json`](anchor81_length_screen.json). The 81-pose
test checks only the span between moving anchors against fixed wire length.
It does **not** construct 81 cable shapes or prove bend radius, wall
clearance, fatigue, or a physical elastic equilibrium. The nine wire shapes
are independent static fits; continuous deformations and first-article
retention/abrasion remain open. Thus these films are engineering candidates,
not manufacture or loaded-walking releases.

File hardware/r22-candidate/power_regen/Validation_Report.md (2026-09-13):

# R22 Power + Regen 实际合板验证记录

2026-09-14，KiCad 10.0.6。结论为可编辑设计完成、规则与电气对应验证通过；无样机。当前记录不授予连续电流、回生脉冲、整机低电量、制造良率或运动认证。

## 结构与源等价

原板面积 3900 + 960 = 4860 mm²。合板为 `(0,-10),(28,-10),(28,-15),(50,-15),(50,0),(65,0),(65,60),(0,60)` 阶梯轮廓，面积 4510 mm²，减少 7.20%；65×75 mm 仅为外包矩形，不冒充实面积。保留原 65×60 投影、TDK i7C2W020A120V-P03-R 全尺寸模块和四个 Ø2.2 mm 安装孔 (3,3)、(62,3)、(3,57)、(62,57)。原位向下 65×70 扩展方案因真实负载架/五金冲突被放弃。

84 个元件、292 个实际焊盘实例逐项对值、MPN、编号和网络。删去 Regen W1/W2 板间重复 SERVO_BUS/GND 端接和其四个独立板安装孔；原理图仅去掉重复 GND 电源旗。所有映射见 `merge_mapping.json`。回生编号 +100、独立网 `RG_` 前缀，仅 SERVO_BUS/GND 共享。检查的 110 个源文件 SHA 无变化。源清单仅指现行 `work/r13-electronics/inherited/TDK_Power_R8/` 和 `Regen_R8/`，不是旧生成器。

主板 U3/U4、回生 U105 的 MSOP 焊盘改为 TI DGS0010A 官方 1.45×0.30 mm land，0.5 mm pitch，器件、引脚中心和本体不缩放。依据 [INA226 官方图](https://www.ti.com/lit/ds/symlink/ina226.pdf) DGS0010A 4221984/A，PDF 第39页。C101 换卧装引脚封装但不换料。J1 唯一 MPN 替换：原 SM08B-SRSS-TB(LF)(SN) 侧插通道穿既有 SP3/SP4 导线，实际 BM08B-SRSS-TB(LF)(SN) 顶插在相同 (60,20)/90° 位置通过 HOME 实形筛查；八针网络、配壳和端子不变。[JST SH 官方图](https://www.jst-mfg.com/product/pdf/eng/eSH.pdf) 配对高 6.3 mm，工程预留6.5 mm；保守外包框不等于精确塑料实体。

## 布线与制造

实际四层板，3486 段线、185 个贯通孔；最细线 0.20 mm，零段低于0.20 mm。新信号默认路由避让目标0.205 mm；保留全部电源大电流通道并加宽回生路径；`Main_Copper_Preservation.json` 独立核对源 BAT_SW/REG_RAW/MID_DRAIN/PRE_SHUNT/SERVO_BUS 所有≥0.65 mm主干的原中心线和至少原线宽。全部大电流主干走外层。

实际原生叠层总厚1.600 mm：阻焊0.010 / F.Cu0.070 / prepreg0.185 / In1.Cu0.035 / core1.000 / In2.Cu0.035 / prepreg0.185 / B.Cu0.070 / 阻焊0.010 mm。FR4、ENIG；这是工程名义堆叠，制造商须接受外层成品铜最小70 µm、孔壁最小25 µm及总厚公差，不能以“2 oz”推断孔壁厚度。

最终自定义规则明确：全局铜间距最低0.16 mm、所有线宽最低0.20 mm、所有 Zone 参与的间距最低0.20 mm。专门的 Zone 规则避免 KiCad 全局自定义规则覆盖局部铺铜属性的问题。由 kicad-cli 重新铺铜并保存后复验。另作全局0.20 mm严格副本诊断：仅15对局部信号焊盘/逃线/过孔组合为0.175 mm，全部有实际坐标和 UUID，见 `Fabrication_Local_Clearances.json`；涉及 Zone 的不足0.20 mm为0对。这些属于明确的0.16 mm最低制造规则内几何，不是忽略条目或放宽失败规则。

0.2 mm成品孔/0.45 mm焊盘、源热孔和 C10.2 新接地孔有焊盘内过孔，要求 IPC-4761 Type VII 填孔盖铜和平整化，不能按敞孔工艺默认焊接。12个主电流换层孔：x=30.8/31.6/32.4/33.2、y=7.2/8/8.8 mm，成品孔0.3 mm/铜盘0.6 mm，明确25 µm最小孔铜。焊盘和实际内外层铜均存在；没有删地铜换取通过。6个 AWG16 端接保持6 mm铜盘/2.4 mm孔；5个 AWG28 pigtail保持1 mm盘/0.5 mm孔。增加真实焊接占用庭院，信号线还须按接口的独立线束包络固定。

## 电容、插头与热源安装

C101 原件 Panasonic EEUFR1C222，2200 µF/16 V；非25 V。本体名义 D12.5×20 mm，设计上限 D13×22 mm，卧装本体 x=6..28、y中心−3.5、z中心9.1 mm，正面最高z15.6 mm（PCB正面z1.6，元件高14 mm），本体离板1 mm。依据 [Panasonic FR 系列](https://industrial.panasonic.com/cdbs/www-data/pdf/RDF0000/ABA0000C1259.pdf)。正/负成型脚焊孔分别 (1.8,−6)/(1.8,−1)。封口外至少2 mm直脚、弯曲半径至少1 mm，夹具支撑封口；独立绝缘托架承担机械载荷，不能靠两根脚悬臂承重。+X泄压端必须通畅。其上限包络至 RS101 封装包络约1.125 mm、庭院约0.600 mm，夹持/装配偏差及引脚成型需样件和工艺接受。根任务负责与板架相连的独立 PEEK 夹持件，不另加板孔。

RS101 (33,−3.5)、Q101 (43,−3.5)、W103/104 (32,−11.5)/(44,−11.5)。RH 两根 AWG16 先沿+Z直出10 mm；J1顶插直出+Z5 mm、拔插8 mm，然后弯曲R5朝+X。P101..105 先+Z6 mm、再R5朝−Y。所有背部THT引脚/锡脚上限z−1.1 mm，需剪脚实测。母板变换必须使用 R11 选定接口，旧R8世界矩阵不沿用。

外置 RH0501R000FE02 保持实际外置发热源，回生热传感不搬到控制板冒充电阻温度。源65°C电阻、75°C TDK保护边界保持。模块 Tc 点实际高度必须样测，不能用模块最高壳高代替触点。

## 承流、压降和热边界

`Current_Thermal_Screen.json` 由冻结路径几何建立条件计算。W3至W103正向主干约84.606 mm：大部分5 mm、W4邻近14 mm段3.4 mm，外层铜70 µm。20°C纯铜工程电阻约4.492 mΩ；75°C线性温度系数下5.463 mΩ。相对于3 mm初版的6.905 mΩ减少约35%。以上未计端接接触、焊盤电流展开、外线、地回流、MOS和分流器，也未把铜区并联收益当成保证。

仅在母线≤12 V且外阻≥0.99 Ω的前提下，I≤12.121 A；这不证明模拟钳位已保证12 V。此条件下正向主干约54.45 mV、0.660 W@20°C/0.803 W@75°C。12个换层孔按25 µm最小孔壁、均流计算合计截面≥0.2827 mm²、20°C约14.3 mW；孔壁和均流都须检验。2 mΩ分流器约0.294 W。Q101按4.5 V栅压最大3.3 mΩ、25°C计算约0.485 W，热态电阻升高，不能用10 V典型值预算。[CSD18540Q5B 官方数据](https://www.ti.com/lit/ds/symlink/csd18540q5b.pdf)。地回流由四层真实铺铜连通，但零未连线不等于地回流压降/温升已合格。

完整 TDK、LM74800/INA300、电流测量/保护保留，前向10 A为源设计目标，未降低源能力设置；前向限流不能约束电机向母线回生电流。源 R1=2.45 kΩ理论10.7971 V，ITRIM17.4 kΩ约11 A设定的典型误差不能作保证12 A硬上限。回生80.6 kΩ/10 kΩ/2.20 MΩ、REF1.25 V名义导通11.3708 V/关闭11.1876 V保持，参考/比较器/容差/共模/温漂与时延仍须实测边界。

外阻1 Ω在约11.4 V吸收约130 W脉冲，厂家50 W连续额定依赖规定散热器，本机小散热板不能自动承诺50 W。源20 J单事件、30 s滚动60 J的50 Hz积分仅是初始软件估计，不是物理I²t硬界；同时制动、外力回推、线束寄生与低电量瞬态尚未验证。16 V电容耐压也不能代替母线/电机端<12 V动态验收。

## 实际铜区 DC 补核（冻结后只读）

`DC_Copper_Regen_Loop_Final.json` 在冻结板图上联合全部实际铺铜多轮廓/空孔、铜盘、线宽和相关THT/过孔，采用二维铜片网络与32扇区孔壁模型。源、新板均按原生70 µm外铜，新板内层35 µm，孔壁25 µm仍是假定；焊接/端接是理想边界。0.10与0.075 mm两档网格求解残差均收敛。没有跨外置RH、MOS或分流器元件按同一网络短接求解。

| 合板路径 | R20估计范围 / mΩ | 网格变化 |
|---|---:|---:|
| W3 SERVO_BUS → W103 RH+ | 3.959–3.984 | 0.62% |
| W104 RH_LOW → Q101漏极 | 0.289–0.296 | 2.36% |
| Q101源极三脚 → RS101.1/2 | 0.246–0.263 | 6.71% |
| RS101.4 → W2输入GND | 0.3718–0.3719 | 0.032% |
| RS101.4 → W4输出GND | 0.4114–0.4116 | 0.046% |

这些范围仅是两档网格的数值变化，不是制造保证误差。MOS源至分流器的短窄段最敏感（约7%），不能把其小数位当精确载流能力。当前所有地铜均参与求解，未以“总铜面积”或单个细地线替代真实平面回流。以RS101.4→W2为终点组合，约66%净电流从正面经内部孔壁转入内/背层；主要分流孔在(25,2)、(15,3)、(28,1)、(36,6)。P101接地PTH也可承担板内换层电流，这不等于其外部AWG28线承担同样电流；外部并行回路没有在该模型中注入。

12个主换层孔的求解分流为每孔6.69–9.90%，合计100%，与简单均分8.33%有差别，见 `Regen_Transition_Current_Sharing.svg`。条件12V/0.99Ω时最高约1.20A/孔；成品孔壁、接触及热态变化仍须验证。不能仅凭孔数宣称通过。

到输入GND的所选板内铜路合计约4.866mΩ，条件12.121A下铜路总压降约59.0mV、损耗0.715W@20°C/0.870W@75°C，其中地回流约4.51mV、54.6mW@20°C。仍须另加MOS、2mΩ分流器、RH、外线和焊接损耗。

同样方法得到旧Regen内部铜路约2.947mΩ，另加旧Power W4→W2地铜约0.096mΩ，合计3.043mΩ；这**未计旧两板之间的正负导线及端接**。新板铜路比该不完整旧铜基线多约1.823mΩ，同时移除了板间线对。只有取得那段真实线束/接点电阻，才可比较完整旧新回路；此记录没有据缺失线阻宣称总体降阻或能力提升。热和实际钳位上界仍未证。

## 新鲜验证与接受状态

最终原生全量 DRC、全部严重级别、未连线、原理图对应均0；原来5项ignore已在交付项目中全部开启为warning，0个排除项用于通过。ERC全严重级别0。`verification/enabled/` 为精确副本复验，`verification/nominal_0p20/` 为单独的更严格局部制造诊断，不能把后者15条当成原规则通过报告。PDF/SVG由最终原生导出，前后铜和装配图已人工查看。源SHA及交付文件SHA另列。

已完成的是工程文件、等价/规则/几何检查和带明确假设的电热筛查。未完成：制造商堆叠/孔铜/填孔工艺接受、样机四线电阻与满载温升、低电量/电源切换/回生波形、实际线束和电容工艺样件、传感器接触、振动、全运动与行走验收。不得据本记录采购额外器件或发布量产/运动合格结论。

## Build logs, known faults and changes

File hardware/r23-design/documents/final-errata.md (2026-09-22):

# R23 最终交付勘误

W1 与第二滚转轴承导轨在整个指定关节盒中的最小保守间隙下界为 **2.275125963 mm**，仍超过本轮 2.2 mm 检查目标。此前部分摘要和线束补充目录的 README 写成 2.493111109 mm；该值是某个子盒的下界，不是所有子盒的最小值。

唯一数值来源为 `harness/dynamic_relief_final/dynamic_check.json` 第一项 `minimum_certified_gap_mm`，并已逐项核对等于 `accepted_subboxes[].lower_bound_mm` 的最小值。最终 8 页线束 PDF 中的 2.275126 mm 正确。此勘误不改变导线几何、裁线长度、半径或端接工艺；冻结原始文件保留用于追溯，交付说明与本勘误优先于旧摘要。

S03 对颈俯仰导轨下界 3.746262511 mm，H05 对嘴部承载件下界 2.417452399 mm。整机其他间隙仍按最终刚体与柔性报告分别使用，不能把三对目标值推广到全机。

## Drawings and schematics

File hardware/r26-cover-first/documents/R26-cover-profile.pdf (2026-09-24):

## OpenDuck R26 · A / thigh-cover profile Mounting holes and installed plane unchanged

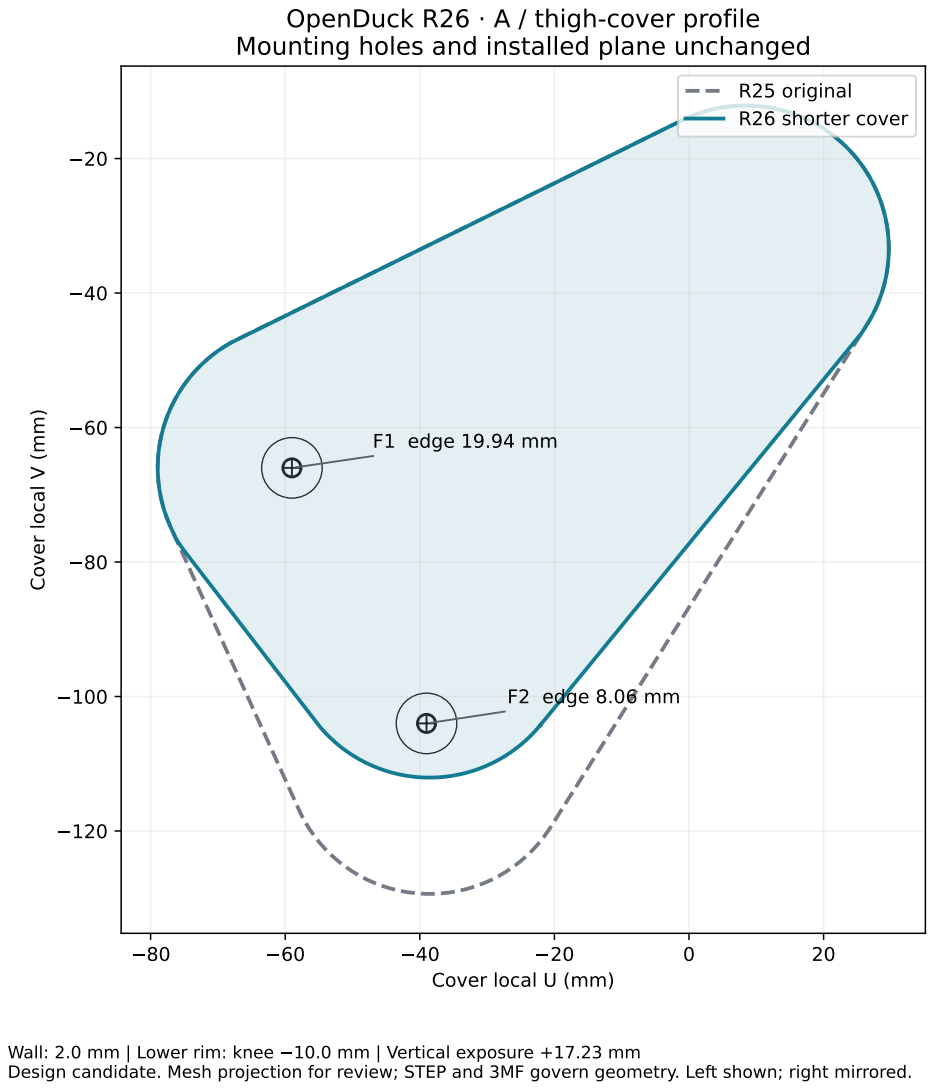
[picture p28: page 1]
R25 original; R26 shorter cover; Wall: 2.0 mm | Lower rim: knee; 10.0 mm | Vertical exposure +17.23 mm

Cover local V (mm)

F1 edge 19.94 mm

F2 edge 8.06 mm

Cover local U (mm)

Design candidate. Mesh projection for review; STEP and 3MF govern geometry. Left shown; right mirrored.

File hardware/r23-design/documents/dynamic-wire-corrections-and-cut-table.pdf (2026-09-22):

R23 | ·
W1 R23-056 | S03 R23-013 | 354 | 14

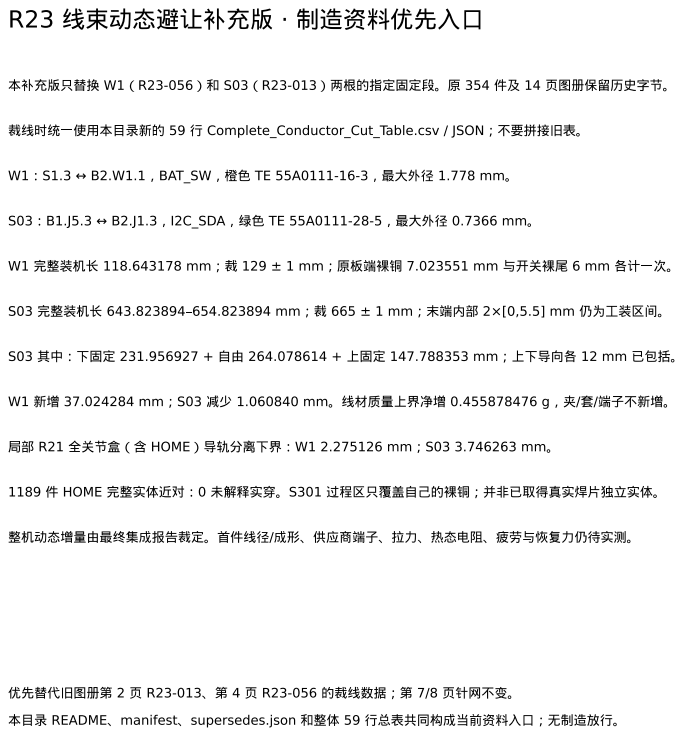
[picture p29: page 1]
Complete_Conductor_Cut_Table.csv / JSON; B2.W1.1 BAT_SW; B2.J1.3 I2C_SDA; HOME; README manifest supersedes.json

W1 | R12 | PTH | S301

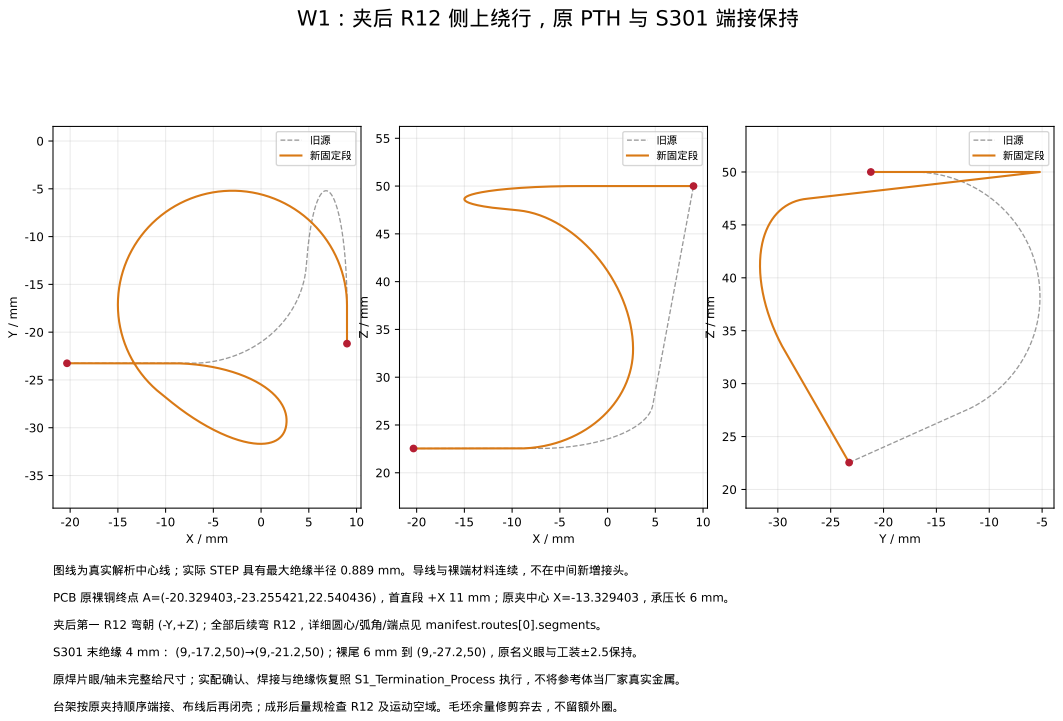
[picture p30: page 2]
STEP; PCB; manifest.routes[0].segments; S1_Termination_Process

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

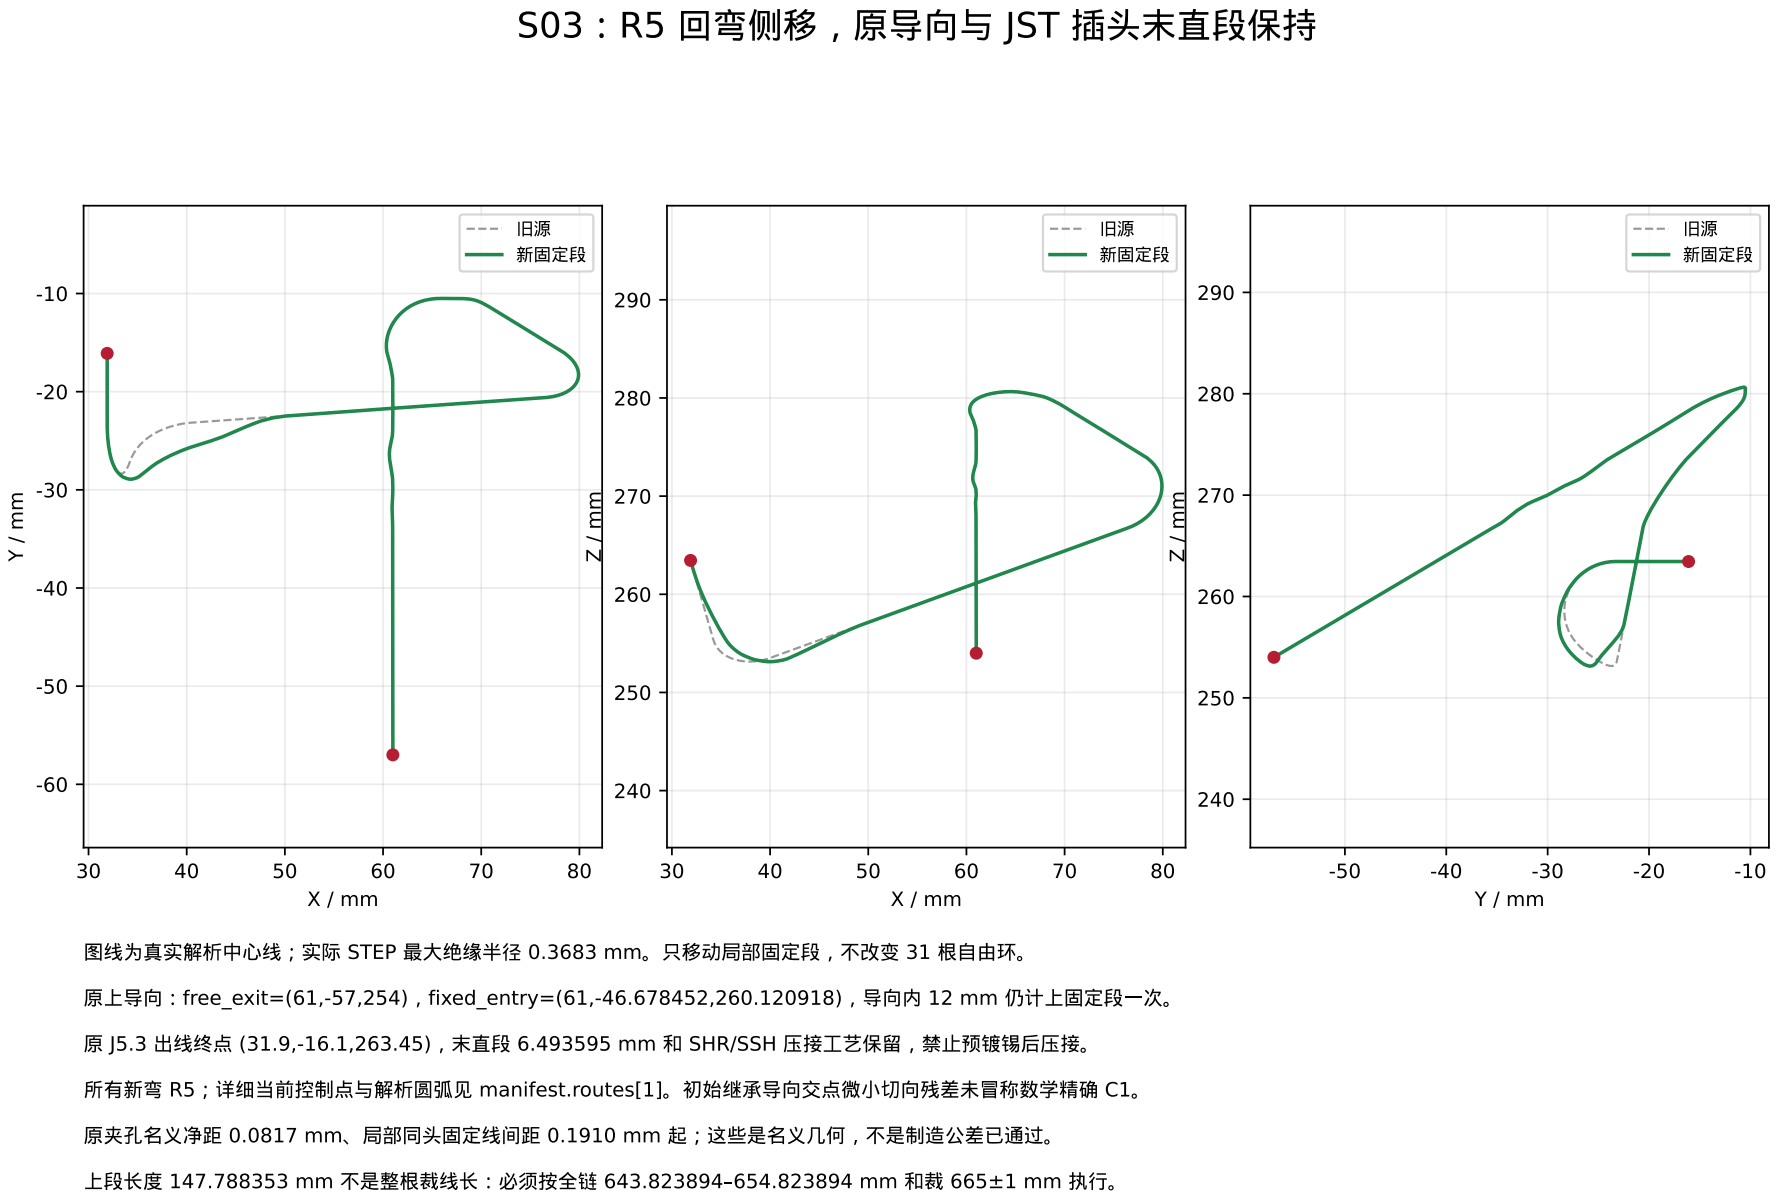
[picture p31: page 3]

59 | 1/5 ·

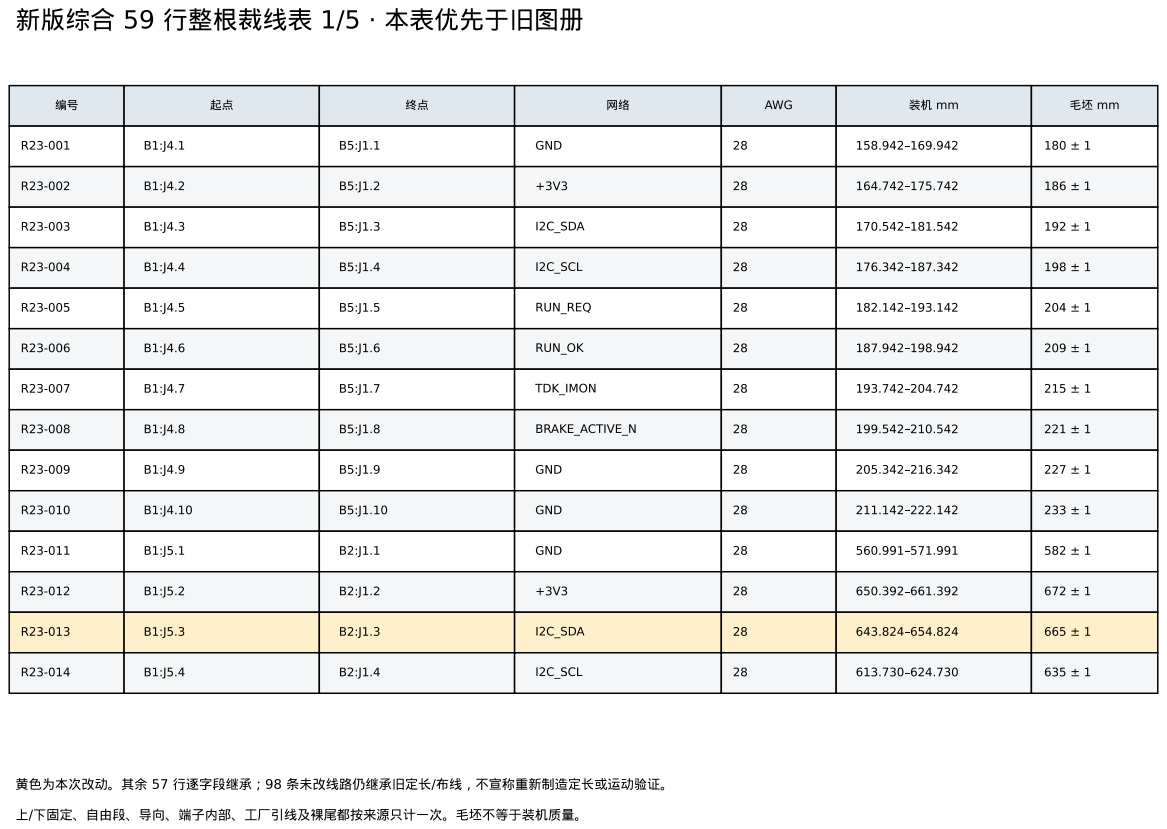
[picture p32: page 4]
AWG; GND; I2C_SDA; I2C_SCL; RUN_REQ; RUN_OK; TDK_IMON; BRAKE_ACTIVE_N

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

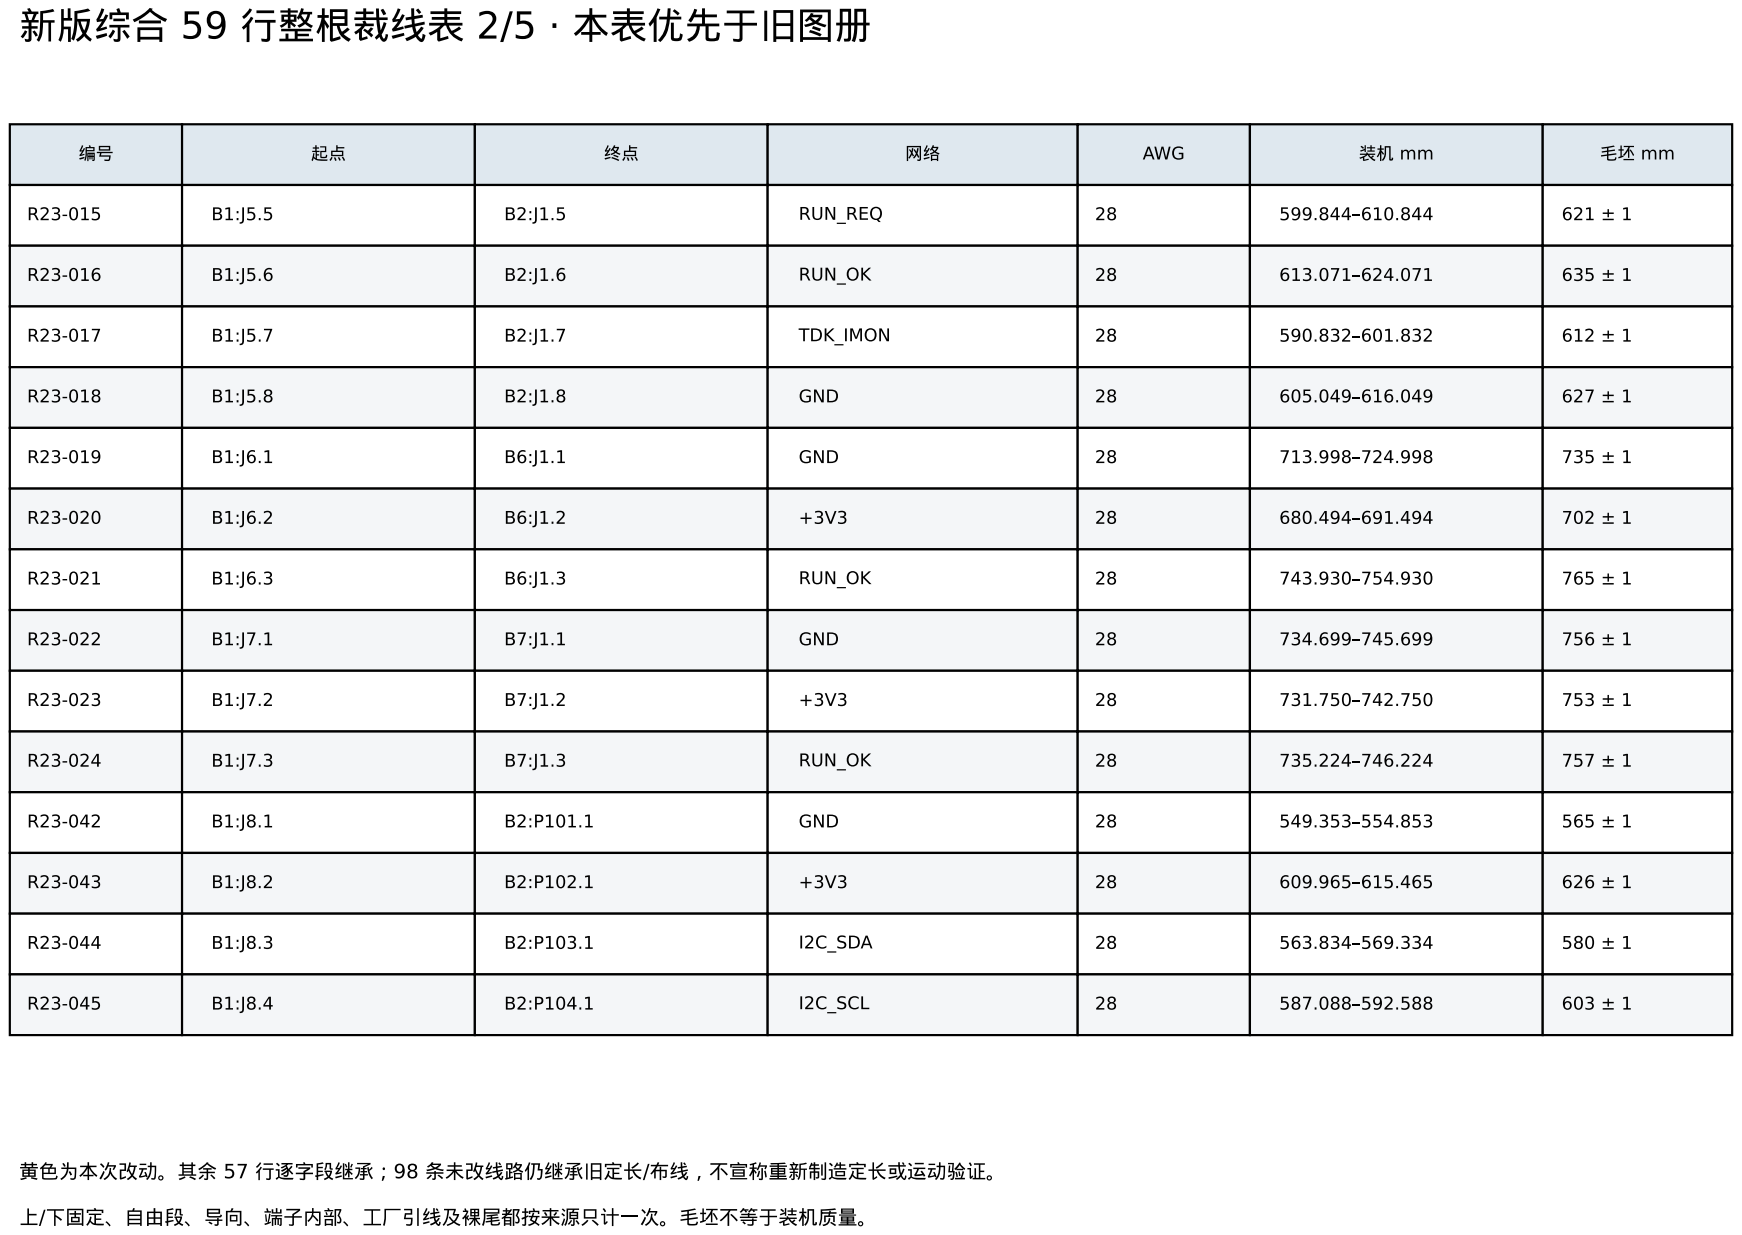
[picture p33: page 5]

59 | 3/5 ·

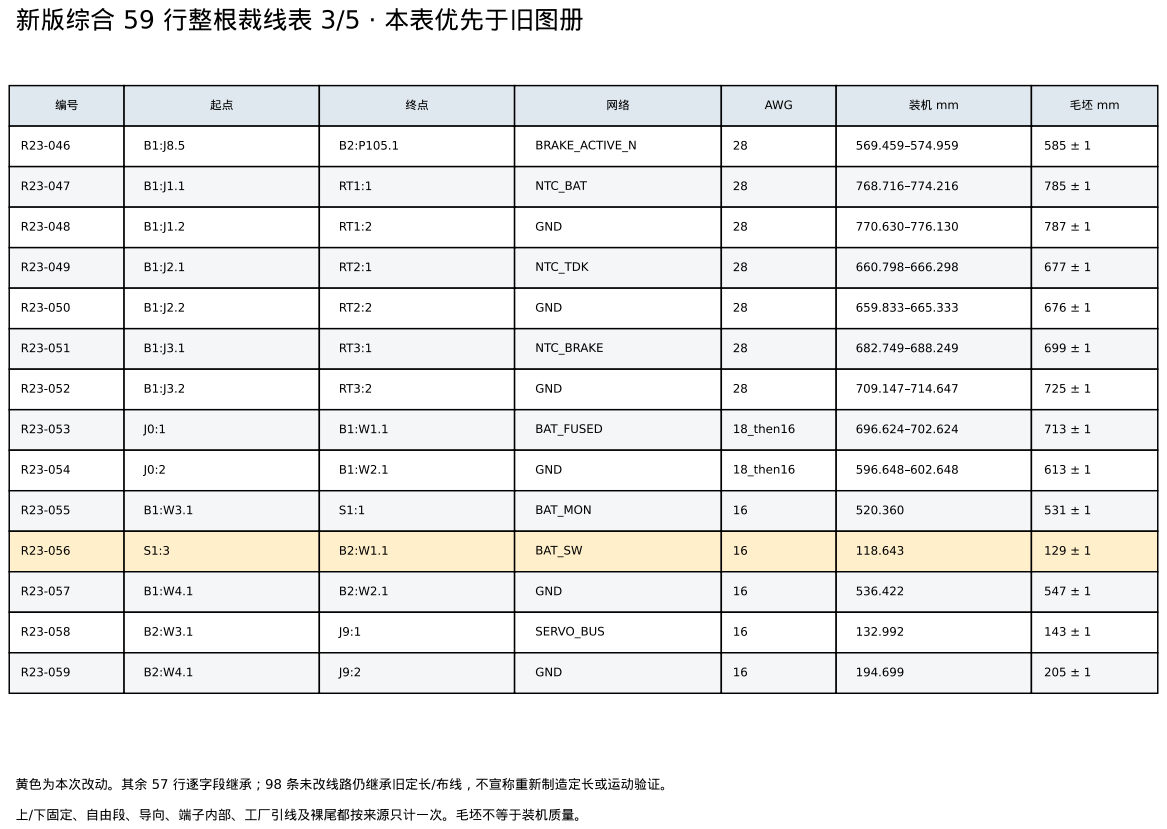
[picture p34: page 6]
AWG; BRAKE_ACTIVE_N; NTC_BAT; GND; NTC_TDK; NTC_BRAKE; BAT_FUSED; 18_then16; BAT_MON; BAT_SW; SERVO_BUS

59 | 4/5 ·

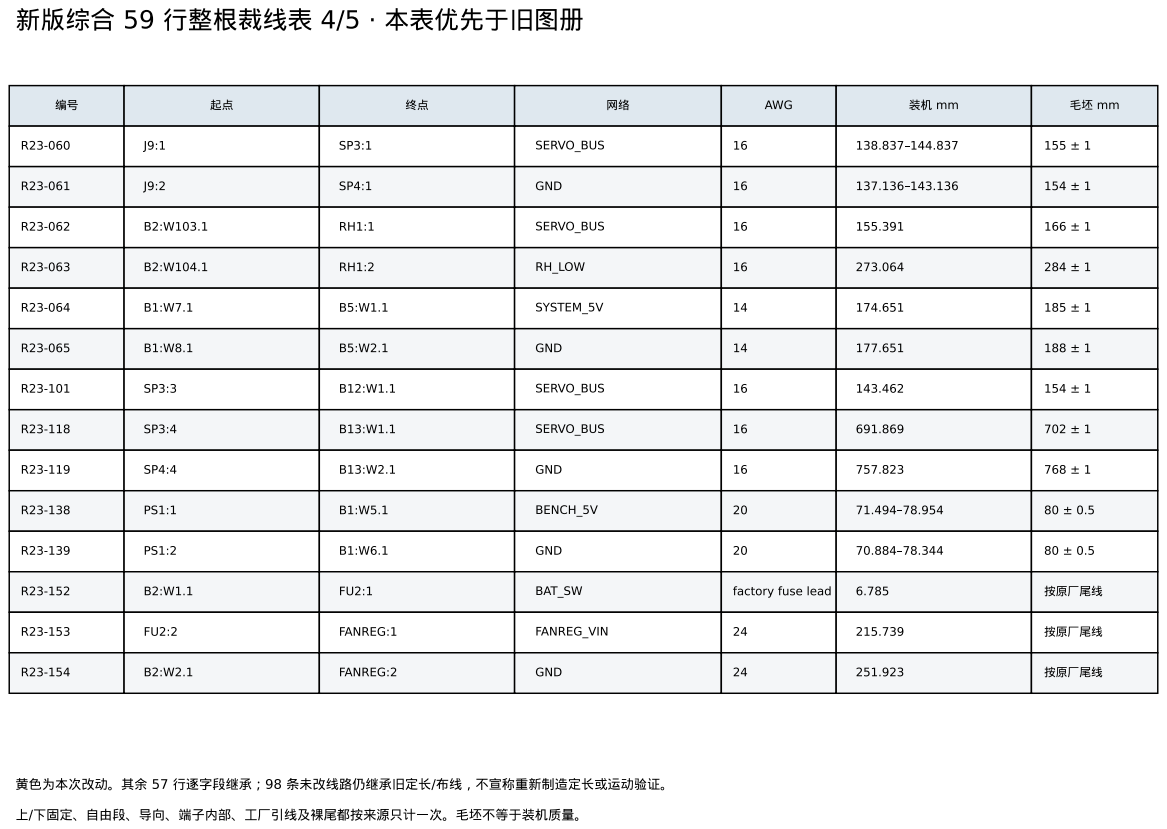
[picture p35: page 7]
AWG; SERVO_BUS; GND; RH_LOW; SYSTEM_5V; BENCH_5V; BAT_SW; factory fuse lead diameter0.64mm 6.785; FANREG:1; FANREG_VIN; FANREG:2

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

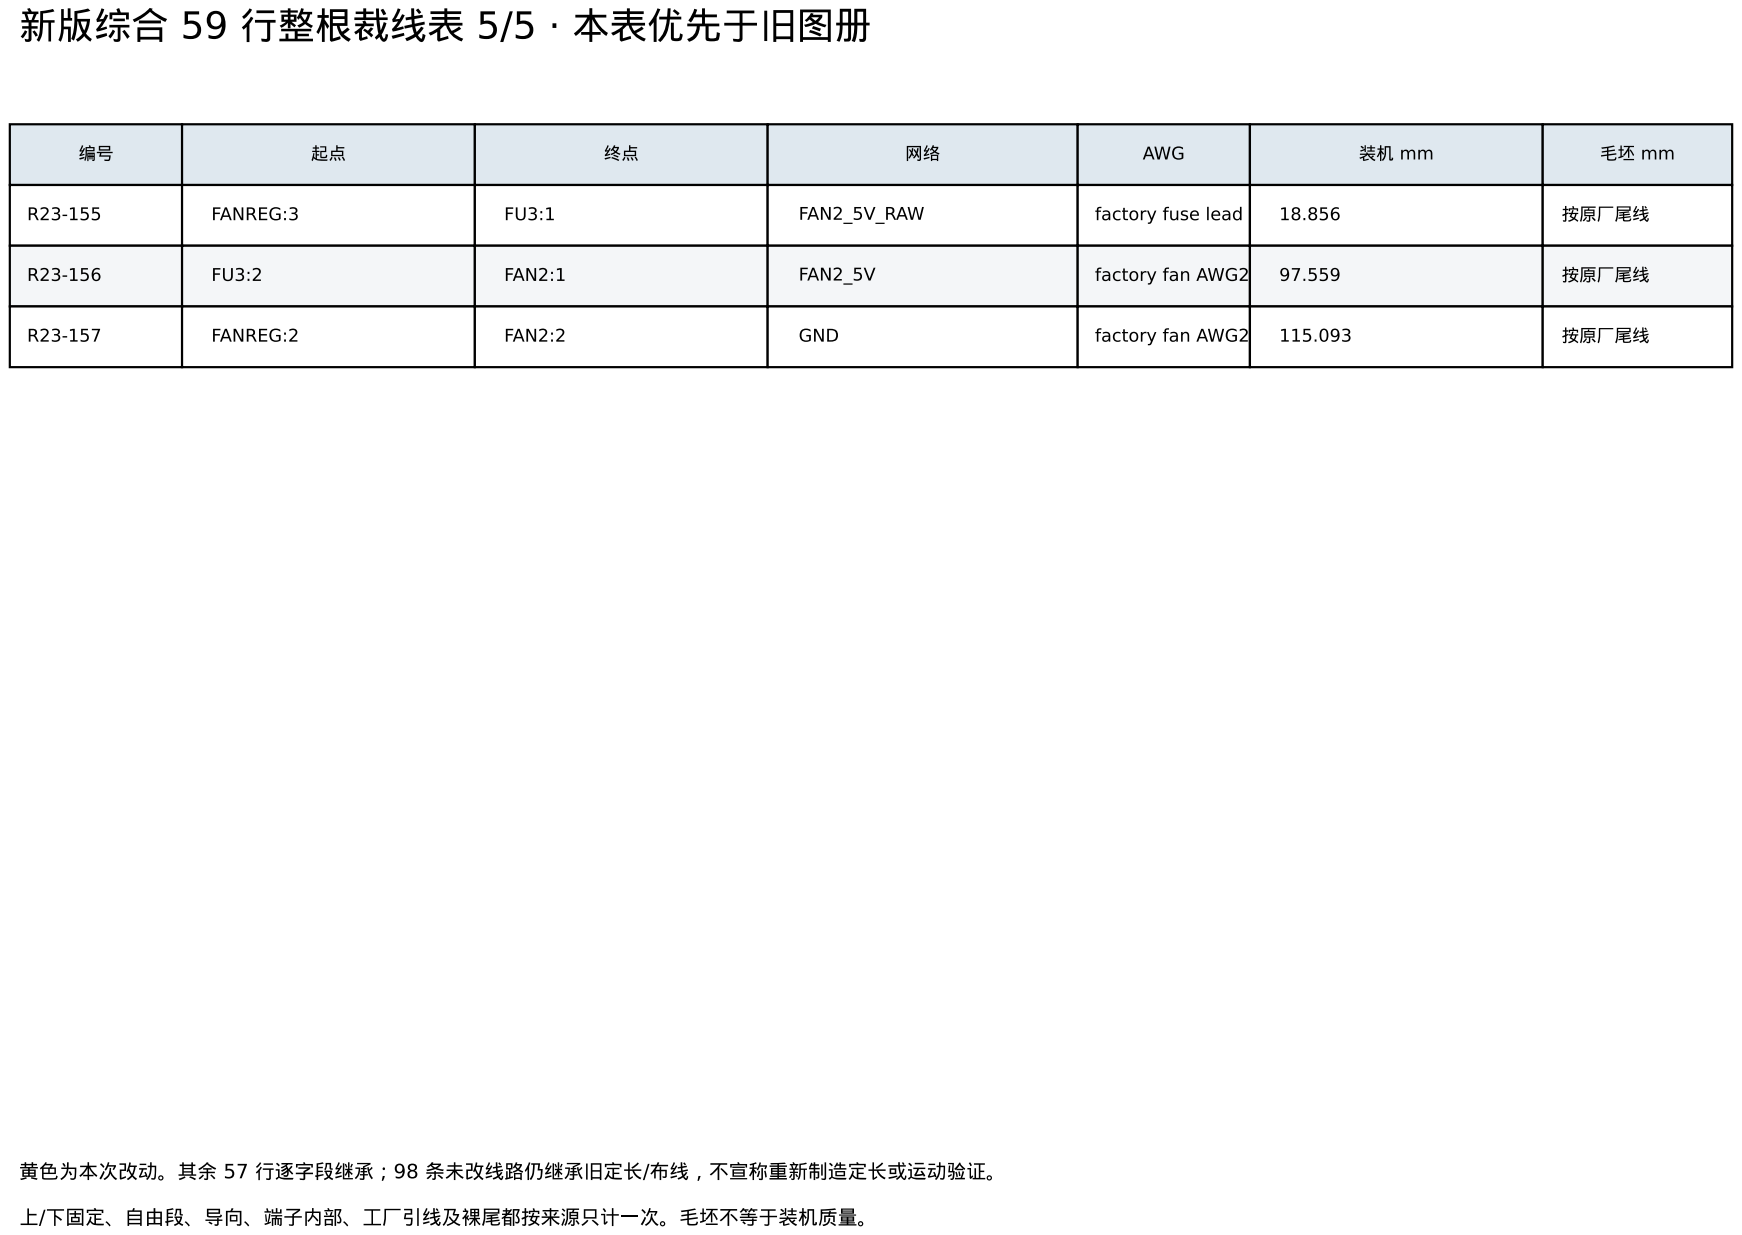
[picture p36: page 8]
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

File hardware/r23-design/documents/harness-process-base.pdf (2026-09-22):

R23

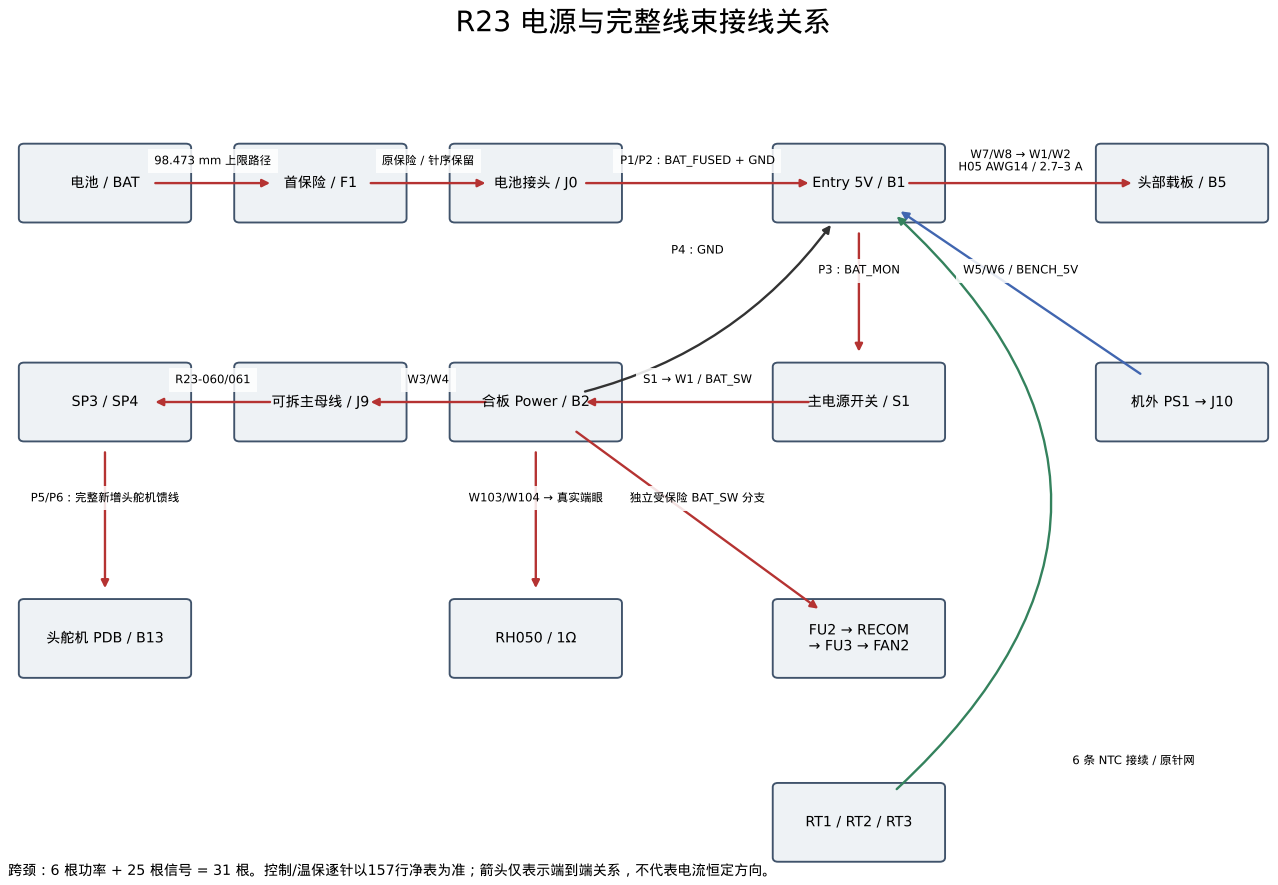
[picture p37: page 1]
/ BAT; Entry 5V / B1; Power / B2; PDB / B13; RECOM; FAN2; P1/P2 BAT_FUSED + GND; H05 AWG14 / 2.7 3 A; P3 BAT_MON; W1 / BAT_SW; P4 GND; BAT_SW; W5/W6 / BENCH_5V; NTC

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

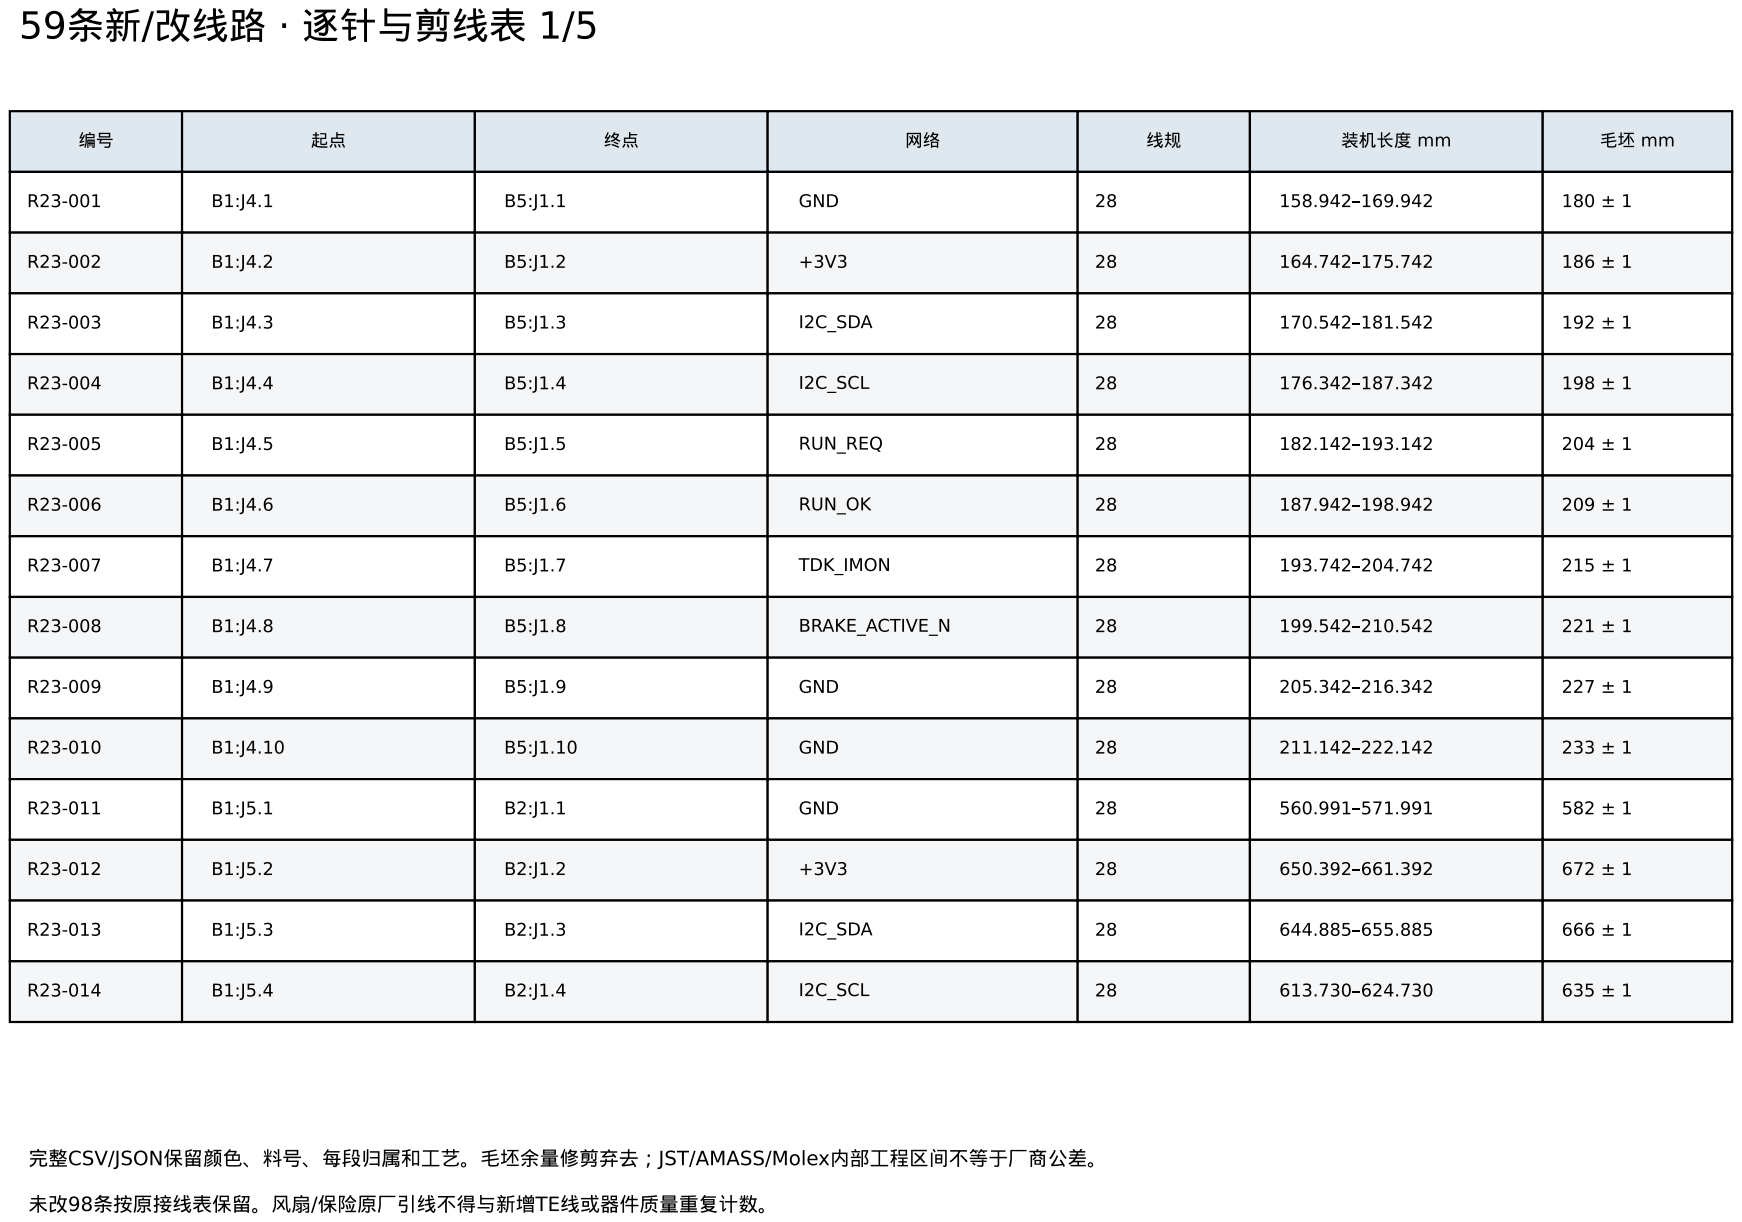
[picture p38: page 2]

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

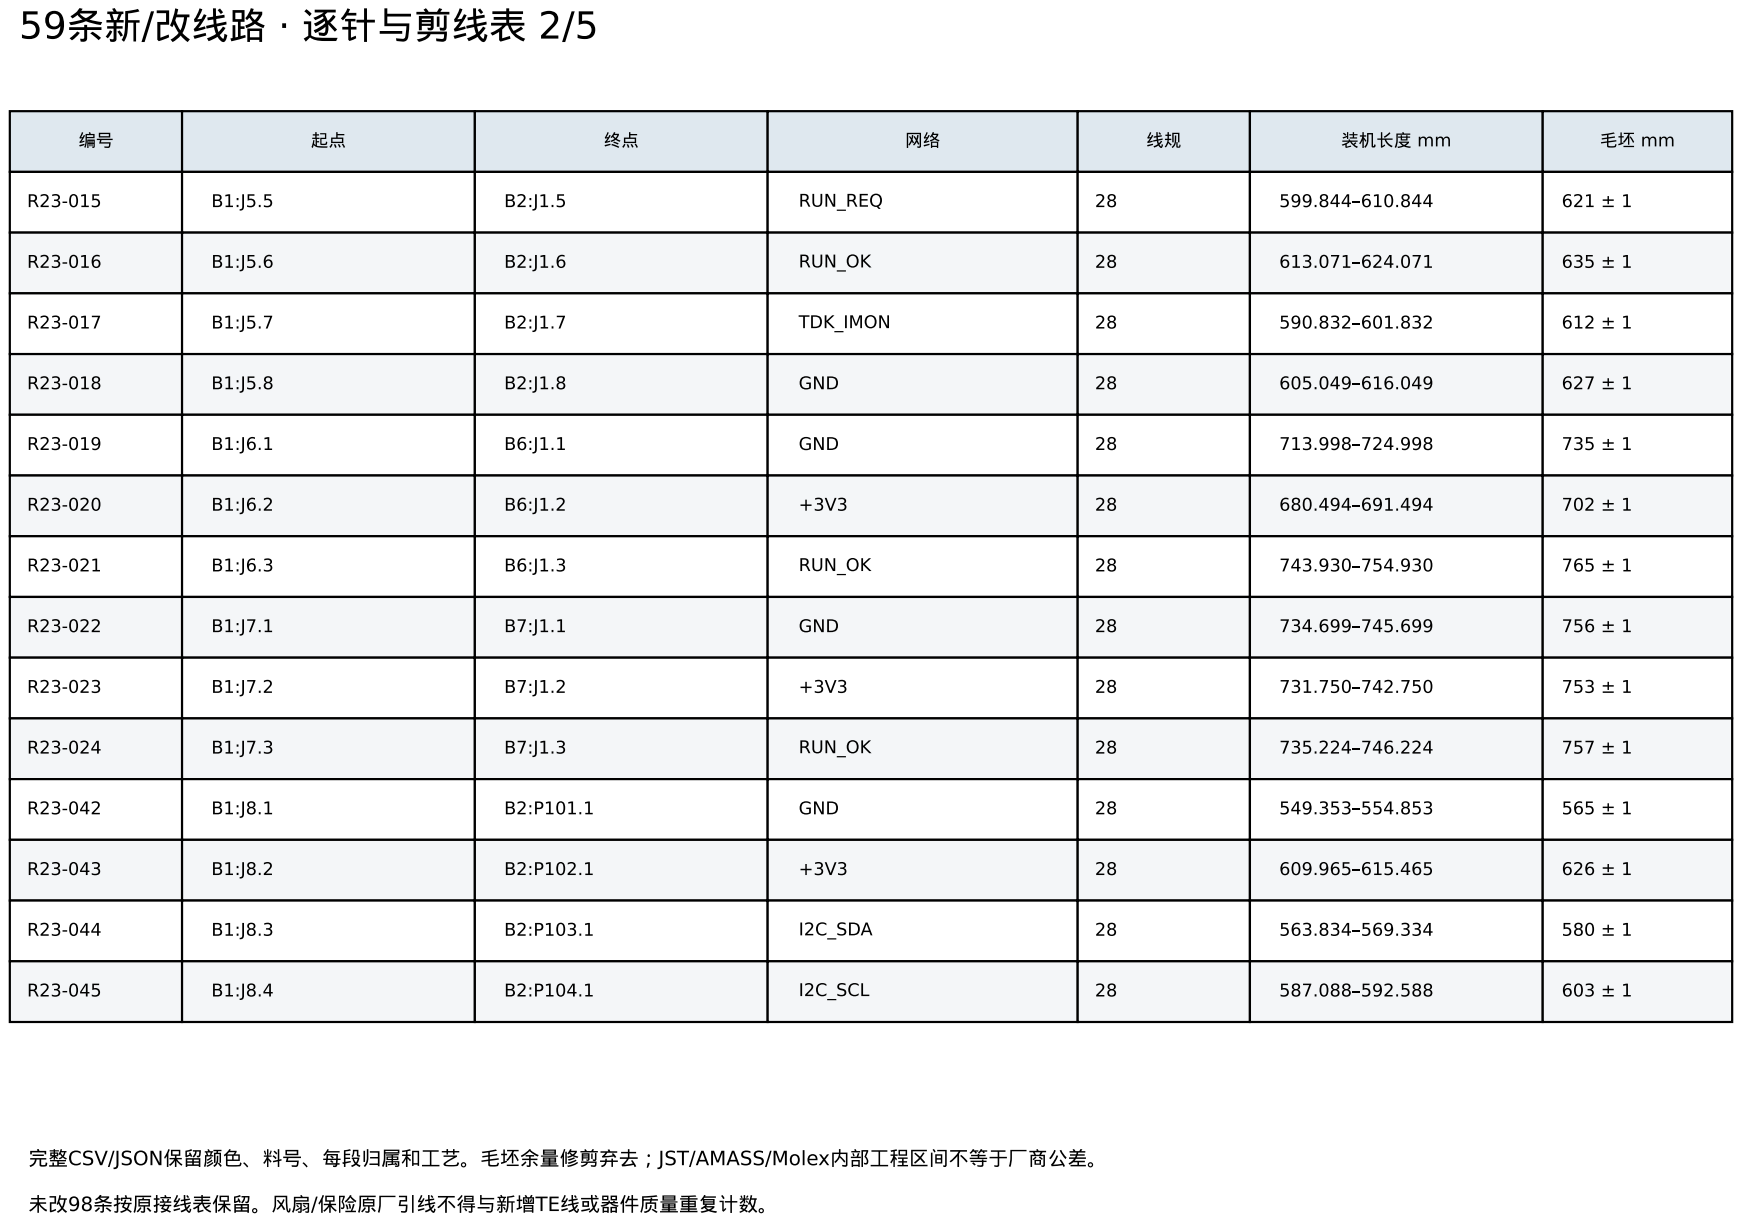
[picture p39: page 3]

59 | / | · | 3/5

CSV/JSON; JST/AMASS/Molex

R23-046 | B1:J8.5 | B2:P105.1 | BRAKE_ACTIVE_N | 28 | 569.459 574.959 | 585 ± 1

R23-047 | B1:J1.1 | RT1:1 | NTC_BAT | 28 | 768.716 774.216 | 785 ± 1

R23-048 | B1:J1.2 | RT1:2 | GND | 28 | 770.630 776.130 | 787 ± 1

R23-049 | B1:J2.1 | RT2:1 | NTC_TDK | 28 | 660.798 666.298 | 677 ± 1

R23-050 | B1:J2.2 | RT2:2 | GND | 28 | 659.833 665.333 | 676 ± 1

R23-051 | B1:J3.1 | RT3:1 | NTC_BRAKE | 28 | 682.749 688.249 | 699 ± 1

R23-052 | B1:J3.2 | RT3:2 | GND | 28 | 709.147 714.647 | 725 ± 1

R23-053 | J0:1 | B1:W1.1 | BAT_FUSED | 18_then16 | 696.624 702.624 | 713 ± 1

R23-054 | J0:2 | B1:W2.1 | GND | 18_then16 | 596.648 602.648 | 613 ± 1

R23-055 | B1:W3.1 | S1:1 | BAT_MON | 16 | 520.360 | 531 ± 1

R23-056 | S1:3 | B2:W1.1 | BAT_SW | 16 | 81.619 | 92 ± 1

R23-057 | B1:W4.1 | B2:W2.1 | GND | 16 | 536.422 | 547 ± 1

R23-058 | B2:W3.1 | J9:1 | SERVO_BUS | 16 | 132.992 | 143 ± 1

R23-059 | B2:W4.1 | J9:2 | GND | 16 | 194.699 | 205 ± 1

59 | / | · | 4/5

CSV/JSON; JST/AMASS/Molex

R23-060 | J9:1 | SP3:1 | SERVO_BUS | 16 | 138.837 144.837 | 155 ± 1

R23-061 | J9:2 | SP4:1 | GND | 16 | 137.136 143.136 | 154 ± 1

R23-062 | B2:W103.1 | RH1:1 | SERVO_BUS | 16 | 155.391 | 166 ± 1

R23-063 | B2:W104.1 | RH1:2 | RH_LOW | 16 | 273.064 | 284 ± 1

R23-064 | B1:W7.1 | B5:W1.1 | SYSTEM_5V | 14 | 174.651 | 185 ± 1

R23-065 | B1:W8.1 | B5:W2.1 | GND | 14 | 177.651 | 188 ± 1

R23-101 | SP3:3 | B12:W1.1 | SERVO_BUS | 16 | 143.462 | 154 ± 1

R23-118 | SP3:4 | B13:W1.1 | SERVO_BUS | 16 | 691.869 | 702 ± 1

R23-119 | SP4:4 | B13:W2.1 | GND | 16 | 757.823 | 768 ± 1

R23-138 | PS1:1 | B1:W5.1 | BENCH_5V | 20 | 71.494 78.954 | 80 ± 0.5

R23-139 | PS1:2 | B1:W6.1 | GND | 20 | 70.884 78.344 | 80 ± 0.5

R23-152 | B2:W1.1 | FU2:1 | BAT_SW | factory fuse lead | diameter0.64mm 6.785

R23-153 | FU2:2 | FANREG:1 | FANREG_VIN | 24 | 215.739

R23-154 | B2:W2.1 | FANREG:2 | GND | 24 | 251.923

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


157 | 2/6

retained=; replaced=; new=; CSV 98/53/4

R23-029 | B5:J3.1 | B8:J1.1 | GND | black | retained

R23-030 | B5:J3.2 | B8:J1.2 | +3V3 | red | retained

R23-031 | B5:J3.3 | B8:J1.3 | I2S_BCLK | source R13 / labeled pin | index retained

R23-032 | B5:J3.4 | B8:J1.4 | GND | black | retained

R23-033 | B5:J3.5 | B8:J1.5 | I2S_WS | source R13 / labeled pin | index retained

R23-034 | B5:J3.6 | B8:J1.6 | I2S_TX | source R13 / labeled pin | index retained

R23-035 | B5:J3.7 | B8:J1.7 | I2S_RX | source R13 / labeled pin | index retained

R23-036 | B5:J3.8 | B8:J1.8 | AMP_ENABLE | source R13 / labeled pin | index retained

R23-037 | B8:J4.1 | B9:J1.1 | GND | black | retained

R23-038 | B8:J4.2 | B9:J1.2 | +3V3 | red | retained

R23-039 | B8:J4.3 | B9:J1.3 | I2S_BCLK | source R13 / labeled pin | index retained

R23-040 | B8:J4.4 | B9:J1.4 | I2S_WS | source R13 / labeled pin | index retained

R23-041 | B8:J4.5 | B9:J1.5 | I2S_RX | source R13 / labeled pin | index retained

R23-042 | B1:J8.1 | B2:P101.1 | GND | black | replaced

R23-043 | B1:J8.2 | B2:P102.1 | +3V3 | red | replaced

R23-044 | B1:J8.3 | B2:P103.1 | I2C_SDA | green | replaced

R23-045 | B1:J8.4 | B2:P104.1 | I2C_SCL | yellow | replaced

R23-046 | B1:J8.5 | B2:P105.1 | BRAKE_ACTIVE_N | brown | replaced

R23-047 | B1:J1.1 | RT1:1 | NTC_BAT | white | replaced

R23-048 | B1:J1.2 | RT1:2 | GND | black | replaced

R23-049 | B1:J2.1 | RT2:1 | NTC_TDK | white | replaced

R23-050 | B1:J2.2 | RT2:2 | GND | black | replaced

R23-051 | B1:J3.1 | RT3:1 | NTC_BRAKE | white | replaced

R23-052 | B1:J3.2 | RT3:2 | GND | black | replaced

R23-053 | J0:1 | B1:W1.1 | BAT_FUSED | red | replaced

R23-054 | J0:2 | B1:W2.1 | GND | black | replaced

R23-055 | B1:W3.1 | S1:1 | BAT_MON | red | replaced

R23-056 | S1:3 | B2:W1.1 | BAT_SW | orange | replaced

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

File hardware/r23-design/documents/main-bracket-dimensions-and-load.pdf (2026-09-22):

R23-MECH-001B | mm |; STEP; Power

delta Y / mm; delta Z / mm; R23-MECH-001B | mm |; STEP

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

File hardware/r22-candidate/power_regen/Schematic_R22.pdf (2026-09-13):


Only SERVO_BUS and GND cross pages on the board. Regen I2C and 3V3 retain their separate harness pins.

Regen W1/W2 replaced with audited copper; external RH and thermal protection remain external. TDK controller defaults OFF; same threshold parts and protected topology.

UNTESTED ENGINEERING CANDIDATE
Sheet: /
File: Microduck_Power_Regen_R22.kicad_sch
Title: Microduck R22 Combined Power and Regen

Size: A4 | Rev: R22
KiCad E.D.A. 10.0.6 | Id: 1/3


J1 CONTROL 3.3V / RUN DEFAULT OFF

CONTROLLED PROTOTYPE
Sheet: /Power/
File: power.kicad_sch
Title: R22 Protected TDK Regulator / INA226 0x41


3 Q102 OPEN DRAIN BRAKE STATUS

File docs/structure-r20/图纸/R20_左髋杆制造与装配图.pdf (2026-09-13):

R20

HOME X Y; HOME Y Z; HOME X Z; STEP; STL; CAM; CNC; R20-HIP-RAIL-v4 | mm |; CAM / FEA /; | 1/4 | STEP c4df72d788e1

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

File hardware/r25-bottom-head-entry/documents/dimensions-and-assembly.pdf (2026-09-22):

## OpenDuck R25 ·

HOME | 1:1


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

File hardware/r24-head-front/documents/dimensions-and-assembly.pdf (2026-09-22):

R24 | · | /
mm | trunk HOME | 1:1


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











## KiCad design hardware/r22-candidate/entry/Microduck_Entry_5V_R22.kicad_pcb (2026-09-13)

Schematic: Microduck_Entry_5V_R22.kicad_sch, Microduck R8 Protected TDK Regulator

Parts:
C1, C2, C3, C4, C5, C6, C7, C17: 100nF; C_0603_1608Metric; MPN GRM188R71H104KA93D
C8: 100pF C0G; C_0603_1608Metric; MPN GRM1885C1H101JA01D
C9, C10: 10uF 50V X7R; C_1210_3225Metric; MPN GRM32ER71H106KA12L
C11: 100uF 35V; CP_Radial_D8.0mm_P3.50mm; MPN EEUFR1V101
C12, C13, C14, C15: 22uF 25V X7R; C_1210_3225Metric; MPN GRM32ER71E226KE15L
C16: 10uF 10V; C_0805_2012Metric; MPN GRM21BR71A106KE51L
C18: 270uF 10V; CP_Radial_D6.3mm_P2.50mm; MPN EEUFR1A271
F1: 2A 125V LOGIC INPUT; Fuse_Littelfuse_448; MPN 0448002.MR
H1, H2, H3, H4: M2 NPTH; MountingHole_2.2mm_M2; MPN NO PART
J1: NTC BAT 10k 3977K; JST_SH_SM02B-SRSS-TB_1x02-1MP_P1.00mm_Horizontal; MPN SM02B-SRSS-TB(LF)(SN)
J2: NTC TDK 10k 3977K; JST_SH_SM02B-SRSS-TB_1x02-1MP_P1.00mm_Horizontal; MPN SM02B-SRSS-TB(LF)(SN)
J3: NTC BRAKE 10k 3977K; JST_SH_BM02B-SRSS-TB_1x02-1MP_P1.00mm_Vertical; MPN BM02B-SRSS-TB(LF)(SN)
J4: TO CM4 LOGIC CTRL; JST_SH_SM10B-SRSS-TB_1x10-1MP_P1.00mm_Horizontal; MPN SM10B-SRSS-TB(LF)(SN)
J5: TO TDK POWER CTRL; JST_SH_BM08B-SRSS-TB_1x08-1MP_P1.00mm_Vertical; MPN BM08B-SRSS-TB(LF)(SN)
J6, J7: TMP302 THERMAL STOP; JST_SH_BM03B-SRSS-TB_1x03-1MP_P1.00mm_Vertical; MPN BM03B-SRSS-TB(LF)(SN)
J8: BRAKE INA226 0x42 TELEMETRY; JST_SH_BM05B-SRSS-TB_1x05-1MP_P1.00mm_Vertical; MPN BM05B-SRSS-TB(LF)(SN)
R1, R2: 10R 0.1%; R_0603_1608Metric; MPN RT0603BRD0710RL
R3, R4, R5, R14: 10k 0.1%; R_0603_1608Metric; MPN RT0603BRD0710KL
R6, R7, R8, R9: 1k; R_0603_1608Metric; MPN ERJ-3EKF1001V
R10: 41.0k 0.1%; R_0603_1608Metric; MPN RT0603BRD0741KL
R11: 10.0k 0.1%; R_0603_1608Metric; MPN RT0603BRD0710KL
R12: 88.7k 0.1%; R_0603_1608Metric; MPN RT0603BRD0788K7L
R13: 32.4k 0.1%; R_0603_1608Metric; MPN RT0603BRD0732K4L
RS1: 2mOhm 1% 3W KELVIN; WSL2726_Kelvin; MPN WSL27262L000FEA
U1: BATTERY INA226 0x40; TI_DGS0010A_Manufacturer_1p45x0p30; MPN INA226AIDGSR
U2: NTC AND EXCITATION 0x48; TI_DGS0010A_Manufacturer_1p45x0p30; MPN ADS1115IDGSR
U3: 4S to 5.10V 3A MODULE; LMZM33603_RLR; MPN LMZM33603RLRR
U4: BENCH PRIORITY REVERSE BLOCK; TPS2117_DRL; MPN TPS2117DRLR
W1: BAT_FUSED; WirePad_2p4mm_6mm; MPN SOLDER AWG16
W2, W4: GND; WirePad_2p4mm_6mm; MPN SOLDER AWG16
W3: BAT_MON; WirePad_2p4mm_6mm; MPN SOLDER AWG16
W5: BENCH_5V; WirePad_2p4mm_6mm; MPN SOLDER AWG20
W6, W8: GND; WirePad_2p4mm_6mm; MPN SOLDER AWG20
W7: SYSTEM_5V; WirePad_2p4mm_6mm; MPN SOLDER AWG20

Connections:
+3V3: C2.1, C7.1, J4.2 (PIN2), J5.2 (PIN2), J6.2 (PIN2), J7.2 (PIN2), J8.2 (PIN2), R3.1, R4.1, R5.1, R9.1, U1.6 (VS), U2.8 (VDD)
ADC_BAT: C3.1, R6.2, U2.4 (AIN0)
ADC_BRAKE: C5.1, R8.2, U2.6 (AIN2)
ADC_EXC: C6.1, R9.2, U2.7 (AIN3)
ADC_TDK: C4.1, R7.2, U2.5 (AIN1)
AGND_5V: R11.2, R12.2, U3.1 (AGND_INTERNAL)
BAT_FUSED: RS1.1 (I+), W1.1
BAT_MON: F1.1, RS1.4 (I-), U1.8 (VBUS), W3.1
BAT_SENSE_N: R2.1, RS1.3 (S-)
BAT_SENSE_P: R1.1, RS1.2 (S+)
BENCH_5V: C16.1, R13.1, U4.3 (VIN1), U4.5 (MODE), W5.1
BENCH_VALID: R13.2, R14.1, U4.4 (PR1)
BRAKE_ACTIVE_N: J4.8 (PIN8), J8.5 (PIN5)
FB_5V: C8.2, R10.2, R11.1, U3.16 (FB)
GND: C2.2, C3.2, C4.2, C5.2, C6.2, C7.2, C9.2, C10.2, C11.2, C12.2, C13.2, C14.2, C15.2, C16.2, C17.2, C18.2, J1.2 (PIN2), J2.2 (PIN2), J3.2 (PIN2), J4.1 (PIN1), J4.9 (PIN9), J4.10 (PIN10), J5.1 (PIN1), J5.8 (PIN8), J6.1 (PIN1), J7.1 (PIN1), J8.1 (PIN1), R14.2, U1.1 (A1), U1.2 (A0), U1.7 (GND), U2.1 (ADDR), U2.3 (GND), U3.5 (PGND), U3.14 (PGND), U3.15 (PGND), U3.18 (EP_PGND), U4.1 (GND), W2.1, W4.1, W6.1, W8.1
I2C_SCL: J4.4 (PIN4), J5.4 (PIN4), J8.4 (PIN4), U1.5 (SCL), U2.10 (SCL)
I2C_SDA: J4.3 (PIN3), J5.3 (PIN3), J8.3 (PIN3), U1.4 (SDA), U2.9 (SDA)
INA_N: C1.2, R2.2, U1.9 (IN-)
INA_P: C1.1, R1.2, U1.10 (IN+)
LOGIC_VIN: C9.1, C10.1, C11.1, F1.2, U3.2 (EN), U3.4 (VIN)
MOBILE_5V: C8.1, C12.1, C13.1, C14.1, C15.1, R10.1, U3.6 (VOUT), U3.7 (VOUT), U3.8 (EP_VOUT), U4.6 (VIN2)
NTC_BAT: J1.1 (PIN1), R3.2, R6.1
NTC_BRAKE: J3.1 (PIN1), R5.2, R8.1
NTC_TDK: J2.1 (PIN1), R4.2, R7.1
RT_5V: R12.1, U3.3 (RT)
RUN_OK: J4.6 (PIN6), J5.6 (PIN6), J6.3 (PIN3), J7.3 (PIN3)
RUN_REQ: J4.5 (PIN5), J5.5 (PIN5)
SW_INTERNAL: U3.9 (SW), U3.10 (SW), U3.11 (SW)
SYSTEM_5V: C17.1, C18.1, U4.2 (VOUT), U4.7 (VOUT), W7.1
TDK_IMON: J4.7 (PIN7), J5.7 (PIN7)

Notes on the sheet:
R8 CONTROLLED PROTOTYPE / 4S -> 10.8V / ACTIVE CURRENT LATCH + REVERSE BLOCK / SOURCE DATASHEETS REQUIRED
J1.5 RUN_REQ defaults LOW. OC latches via INA300; clear only while RUN_REQ LOW. Brake board mandatory on SERVO_BUS.
TDK ITRIM tolerance is TYPICAL; INA300 provides independent trip. 10A copper target requires physical thermal qualification.

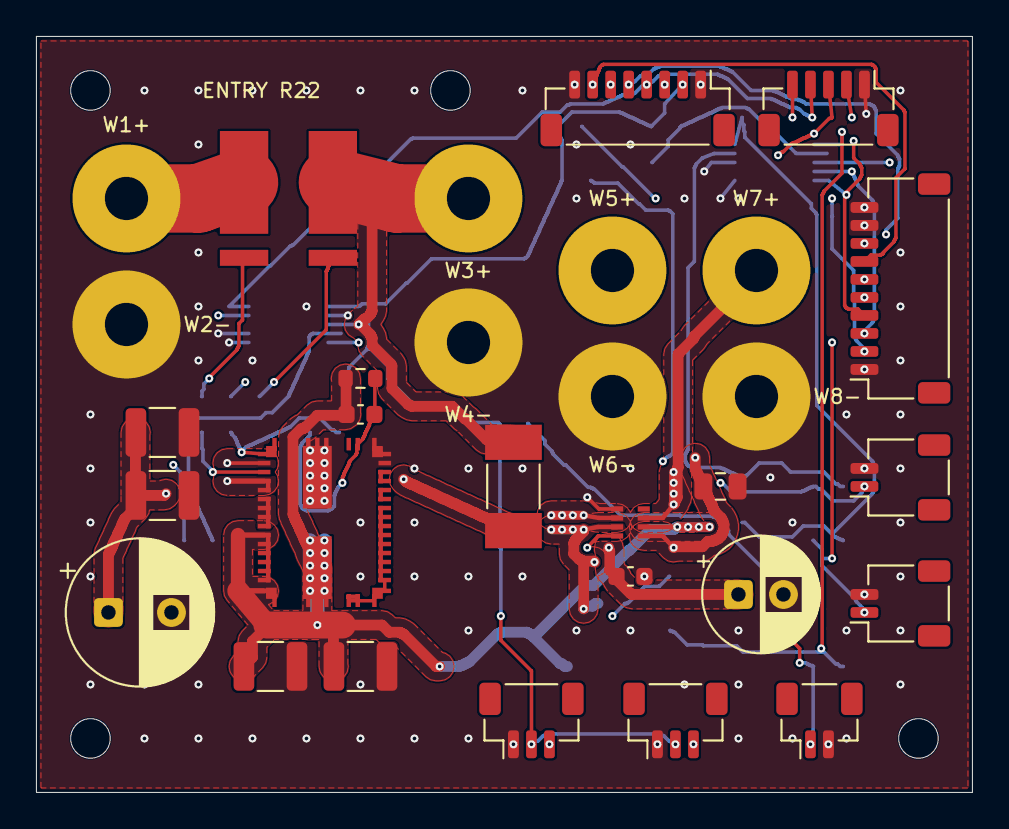
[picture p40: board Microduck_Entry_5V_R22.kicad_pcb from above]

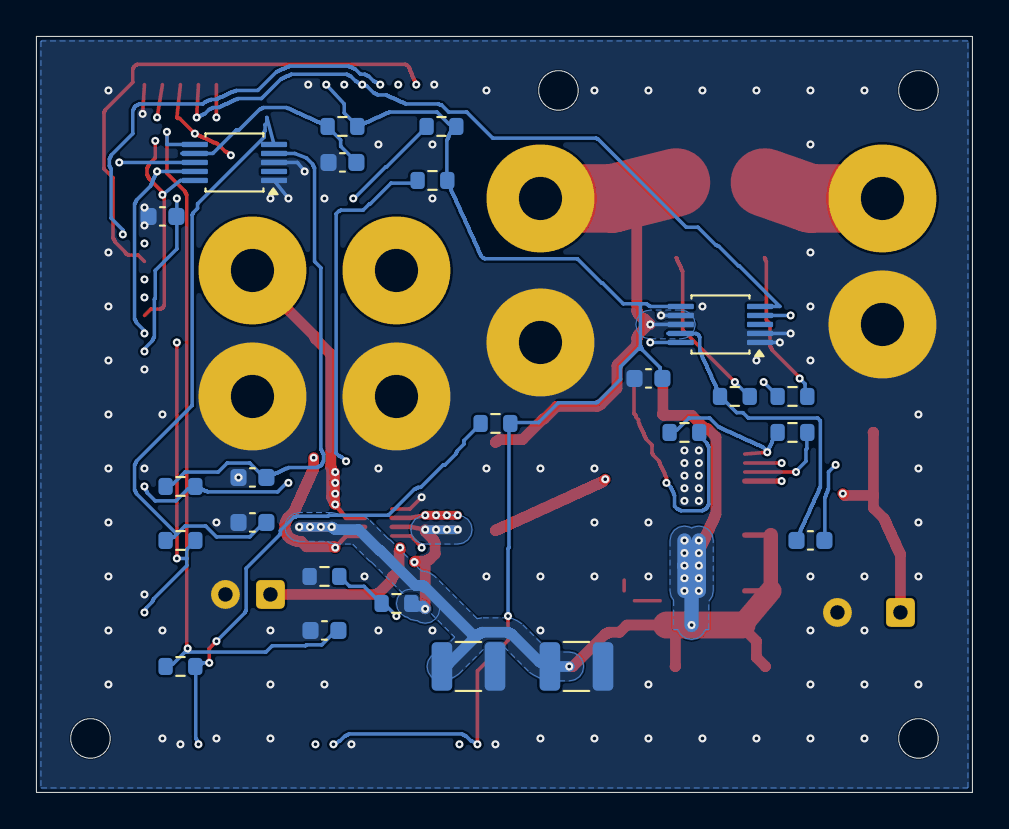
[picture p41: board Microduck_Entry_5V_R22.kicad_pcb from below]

Board: 4 copper layers, 52.0 x 42.0 mm, 58 parts (24 on the bottom side), 30 nets.

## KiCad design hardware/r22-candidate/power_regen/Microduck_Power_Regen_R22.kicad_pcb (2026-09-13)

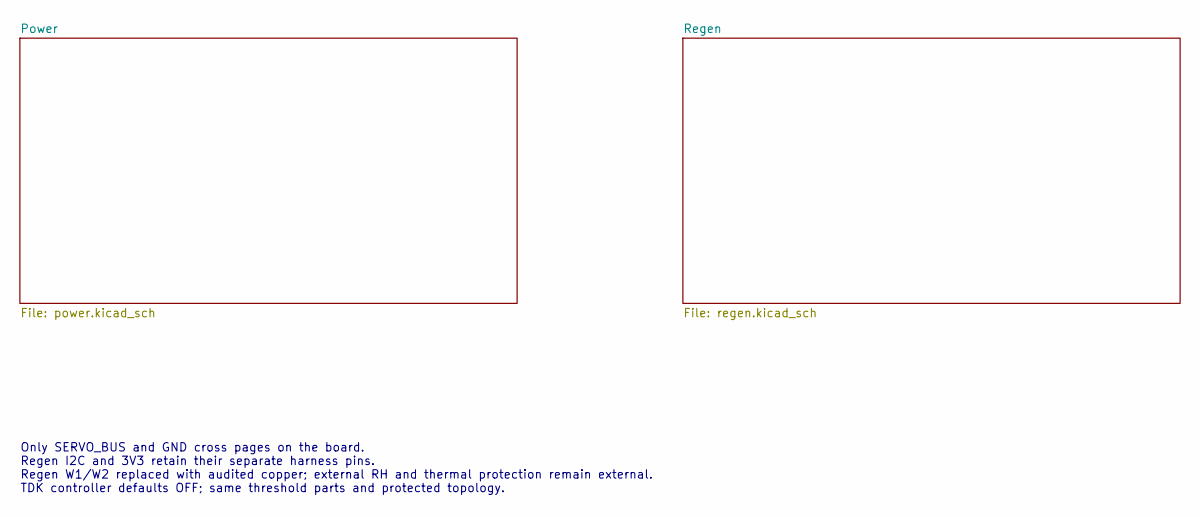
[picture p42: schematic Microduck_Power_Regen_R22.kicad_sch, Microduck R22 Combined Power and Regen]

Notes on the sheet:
Only SERVO_BUS and GND cross pages on the board. Regen I2C and 3V3 retain their separate harness pins. Regen W1/W2 replaced with audited copper; external RH and thermal protection remain external. TDK controller defaults OFF; same threshold parts and protected topology.

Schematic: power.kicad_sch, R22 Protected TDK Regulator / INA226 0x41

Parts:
C1, C2, C3: 680uF 25V 20%; CP_Radial_D10.0mm_P5.00mm; MPN EEUFR1E681
C4, C5, C6, C7, C8, C9, C10, C11, C12, C15: 100nF; C_0603_1608Metric; MPN GRM188R71H104KA93D
C13, C14, C16, C17, C18, C19: 10uF 50V; C_1210_3225Metric; MPN GRM32ER71H106KA12L
H1, H2, H3, H4: M2 NPTH; MountingHole_2.2mm_M2; MPN NO PART
J1: CONTROL 3.3V / RUN DEFAULT OFF; JST_SH_BM08B-SRSS-TB_1x08-1MP_P1.00mm_Vertical; MPN BM08B-SRSS-TB(LF)(SN)
Q1, Q2: 60V 2.2mOhm @10V; CSD18540Q5B_DNK; MPN CSD18540Q5B
Q3: TDK enable sink; SOT-23; MPN BSS138
R1: 2.45k 0.1%; R_0603_1608Metric; MPN RT0603BRD072K45L
R2: 17.4k 0.1%; R_0603_1608Metric; MPN RT0603BRD0717K4L
R3: 1k; R_0603_1608Metric; MPN ERJ-3EKF1001V
R4: 8.38k 0.1%; R_0603_1608Metric; MPN RT0603BRD078K38L
R5: 1k 0.1%; R_0603_1608Metric; MPN RT0603BRD071KL
R6: 1.2k; R_0603_1608Metric; MPN ERJ-3EKF1201V
R7, R8: 100k; R_0603_1608Metric; MPN ERJ-3EKF1003V
R9: 1.10k 0.1%; R_0603_1608Metric; MPN RT0603BRD071K1L
R10, R11: 10R 0.1%; R_0603_1608Metric; MPN RT0603BRD0710RL
RS1: 2mOhm 1% 3W KELVIN; WSL2726_Kelvin; MPN WSL27262L000FEA
U1: TDK i7C2W020A120V-P03-R; TDK_i7C_P03; MPN i7C2W020A120V-P03-R
U2: IDEAL DIODE + OV CUT; WSON-12-1EP_3x3mm_P0.5mm_EP1.5x2.5mm; MPN LM74800QDRRRQ1
U3: SERVO CURRENT / VBUS 0x41; TI_DGS0010A_1p45x0p30; MPN INA226AIDGSR
U4: HARDWARE OC LATCH; TI_DGS0010A_1p45x0p30; MPN INA300AIDGSR
W1: 4S SWITCHED +; WirePad_2p4mm_6mm; MPN SOLDER AWG16
W2: GND INPUT; WirePad_2p4mm_6mm; MPN SOLDER AWG16
W3: SERVO 10.8V; WirePad_2p4mm_6mm; MPN SOLDER AWG16
W4: GND OUTPUT; WirePad_2p4mm_6mm; MPN SOLDER AWG16

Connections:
+3V3: C10.1, C11.1, J1.2 (PIN2), U3.2 (A0), U3.6 (VS), U4.4 (ENABLE), U4.9 (VS)
BAT_SW: C1.1, C12.1, C13.1, C14.1, C16.1, C17.1, C18.1, C19.1, U1.1 (VIN), W1.1
CP_CAP: C5.1, U2.11 (CAP)
DGATE: Q1.4 (G), U2.1 (DGATE)
GND: C1.2, C2.2, C3.2, C4.2, C6.2, C7.2, C8.2, C10.2, C11.2, C12.2, C13.2, C14.2, C15.2, C16.2, C17.2, C18.2, C19.2, J1.1 (PIN1), J1.8 (PIN8), Q3.2 (S), R1.2, R2.2, R5.2, R7.2, R8.2, R9.2, U1.3 (GND), U1.4 (GND), U1.32 (SYNC), U2.7 (GND), U3.1 (A1), U3.7 (GND), U4.8 (GND), W2.1, W4.1; also elsewhere on the board
HGATE: Q2.4 (G), U2.8 (HGATE)
I2C_SCL: J1.4 (PIN4), U3.5 (SCL)
I2C_SDA: J1.3 (PIN3), U3.4 (SDA)
IMON_RAW: R3.1, U1.34 (IMON)
INA_N: C9.2, R11.2, U3.9 (IN-)
INA_P: C9.1, R10.2, U3.10 (IN+)
ITRIM: R2.1, U1.5 (ITRIM)
MID_DRAIN: C5.2, C6.1, Q1.5 (D), Q1.6 (D), Q1.7 (D), Q1.8 (D), Q2.5 (D), Q2.6 (D), Q2.7 (D), Q2.8 (D), R4.1, U2.3 (VSNS), U2.4 (SW), U2.10 (VS), U2.12 (C)
OC_LIMIT: R9.1, U4.3 (LIMIT)
OV_SENSE: R4.2, R5.1, U2.5 (OV)
PRE_SHUNT: C8.1, Q2.1 (S), Q2.2 (S), Q2.3 (S), RS1.1 (I+), U2.9 (OUT)
REG_RAW: C2.1, C3.1, C7.1, C15.1, Q1.1 (S), Q1.2 (S), Q1.3 (S), U1.7 (SENSE+), U1.8 (VOUT), U2.2 (A)
RUN_OK: J1.6 (PIN6), Q3.1 (G), R6.2, R7.1, U2.6 (EN/UVLO), U4.5 (ALERT)
RUN_REQ: J1.5 (PIN5), R6.1, R8.1, U4.6 (LATCH)
SENSE_N: R11.1, RS1.3 (S-), U4.2 (IN-)
SENSE_P: R10.1, RS1.2 (S+), U4.1 (IN+)
SERVO_BUS: RS1.4 (I-), U3.8 (VBUS), W3.1; also elsewhere on the board
TDK_IMON: C4.1, J1.7 (PIN7), R3.2
TDK_ON_N: Q3.3 (D), U1.2 (ON/OFF)
VTRIM: R1.1, U1.6 (TRIM)

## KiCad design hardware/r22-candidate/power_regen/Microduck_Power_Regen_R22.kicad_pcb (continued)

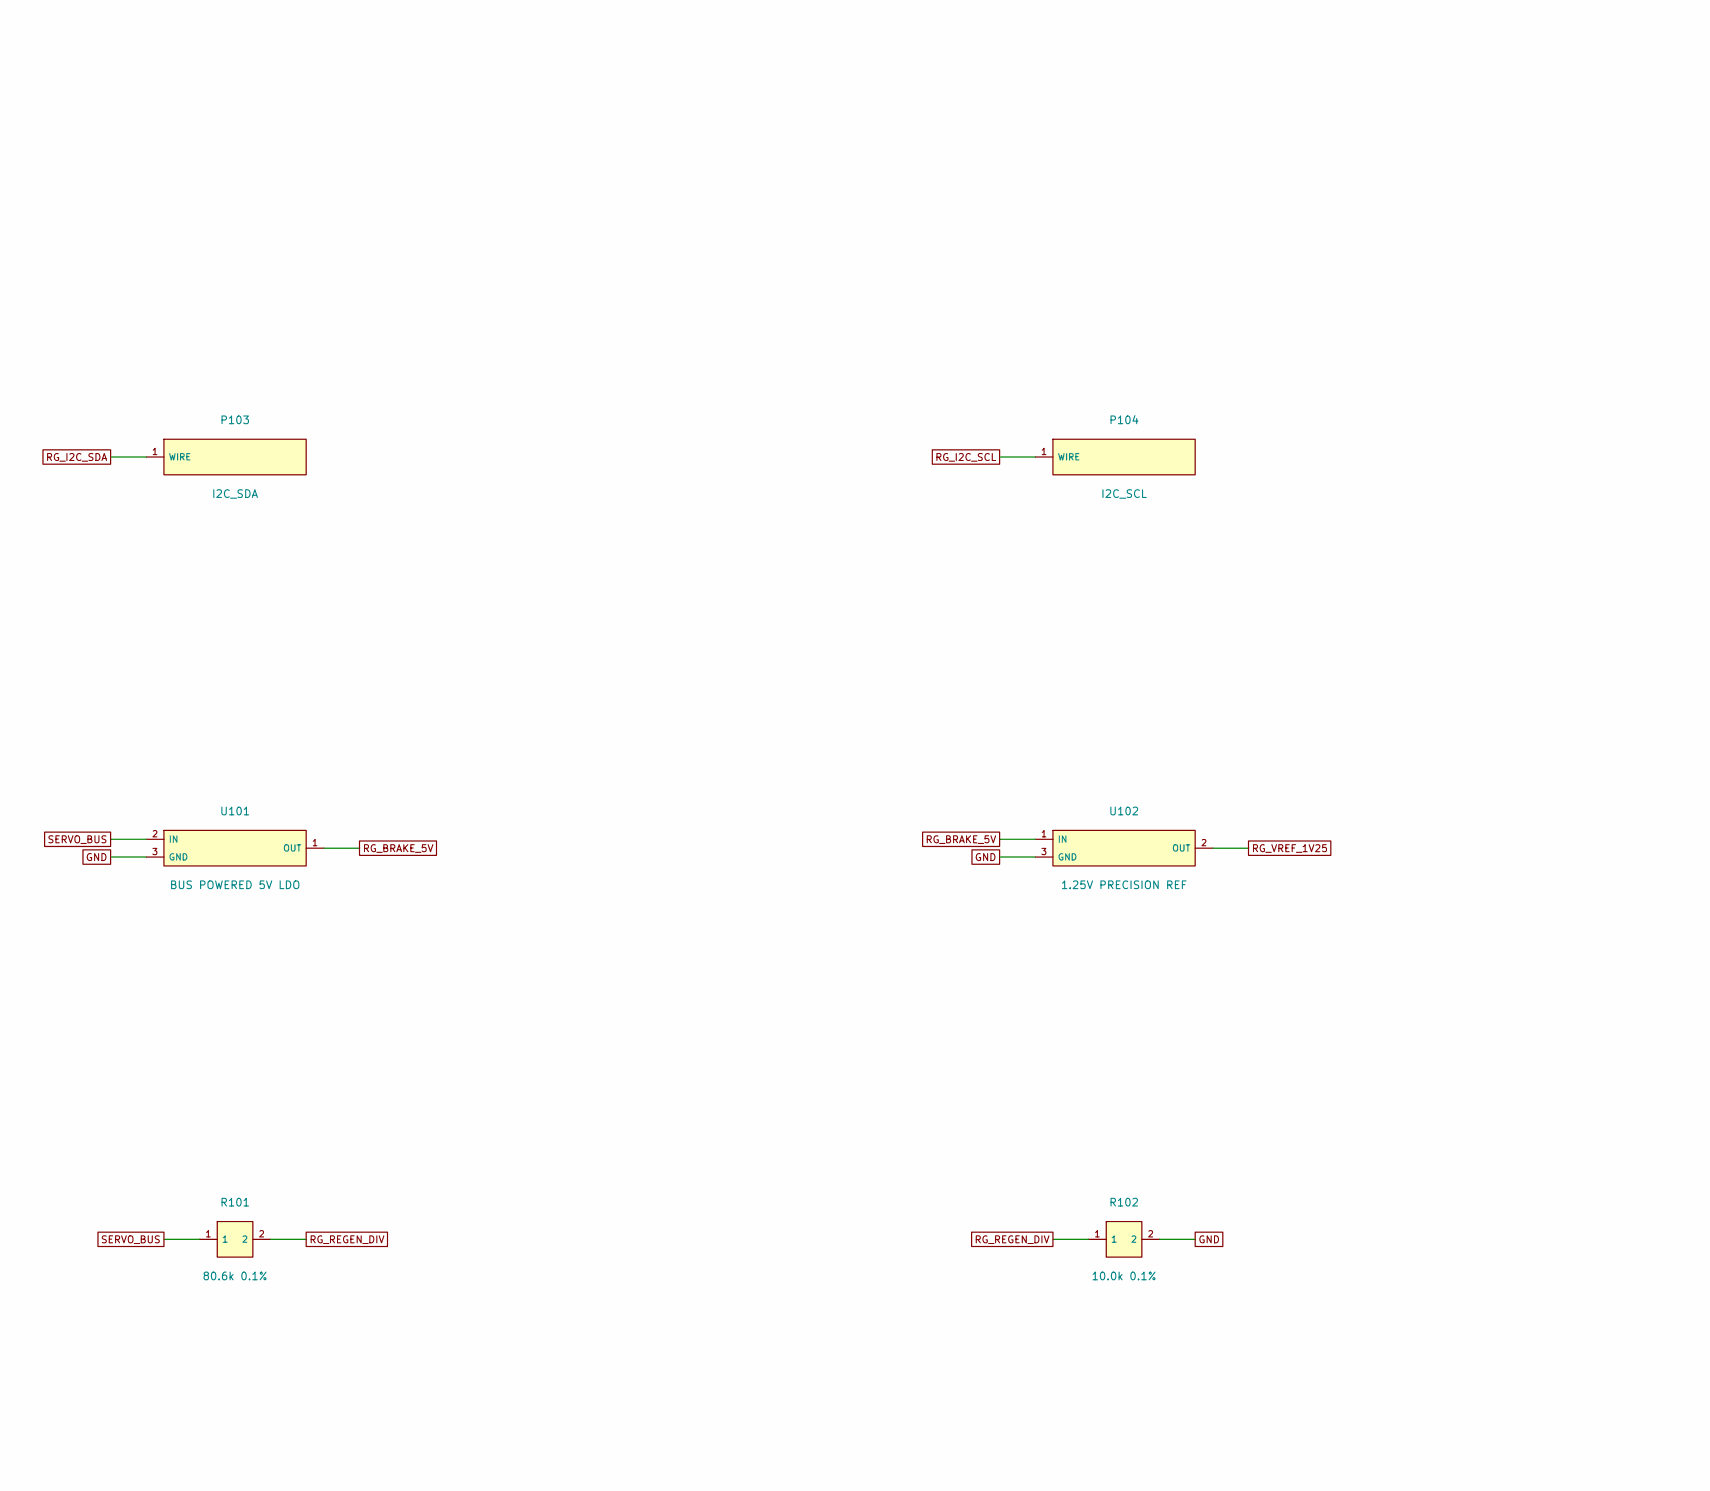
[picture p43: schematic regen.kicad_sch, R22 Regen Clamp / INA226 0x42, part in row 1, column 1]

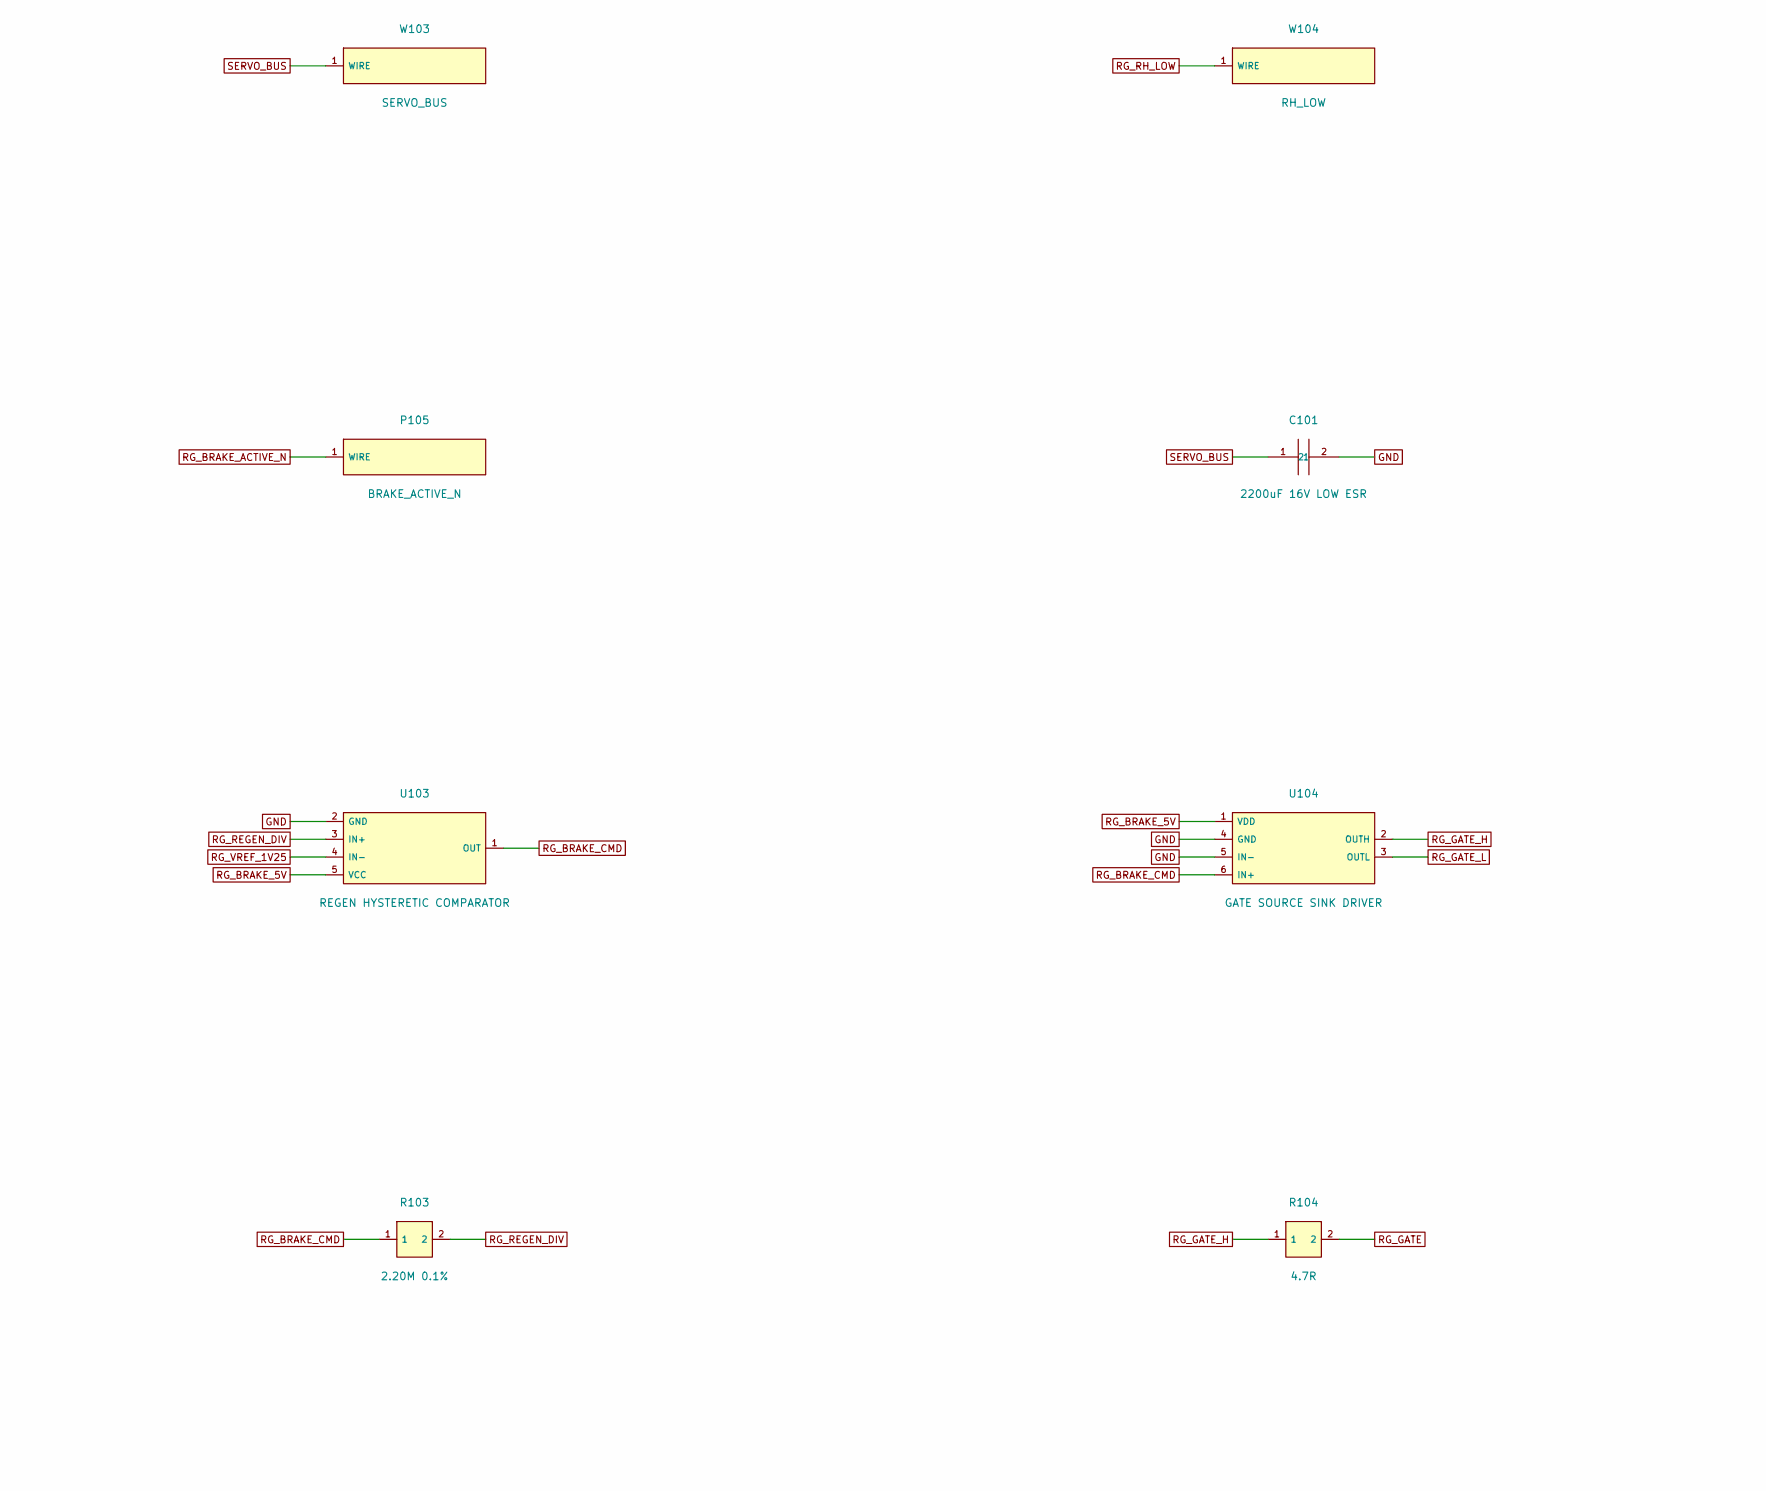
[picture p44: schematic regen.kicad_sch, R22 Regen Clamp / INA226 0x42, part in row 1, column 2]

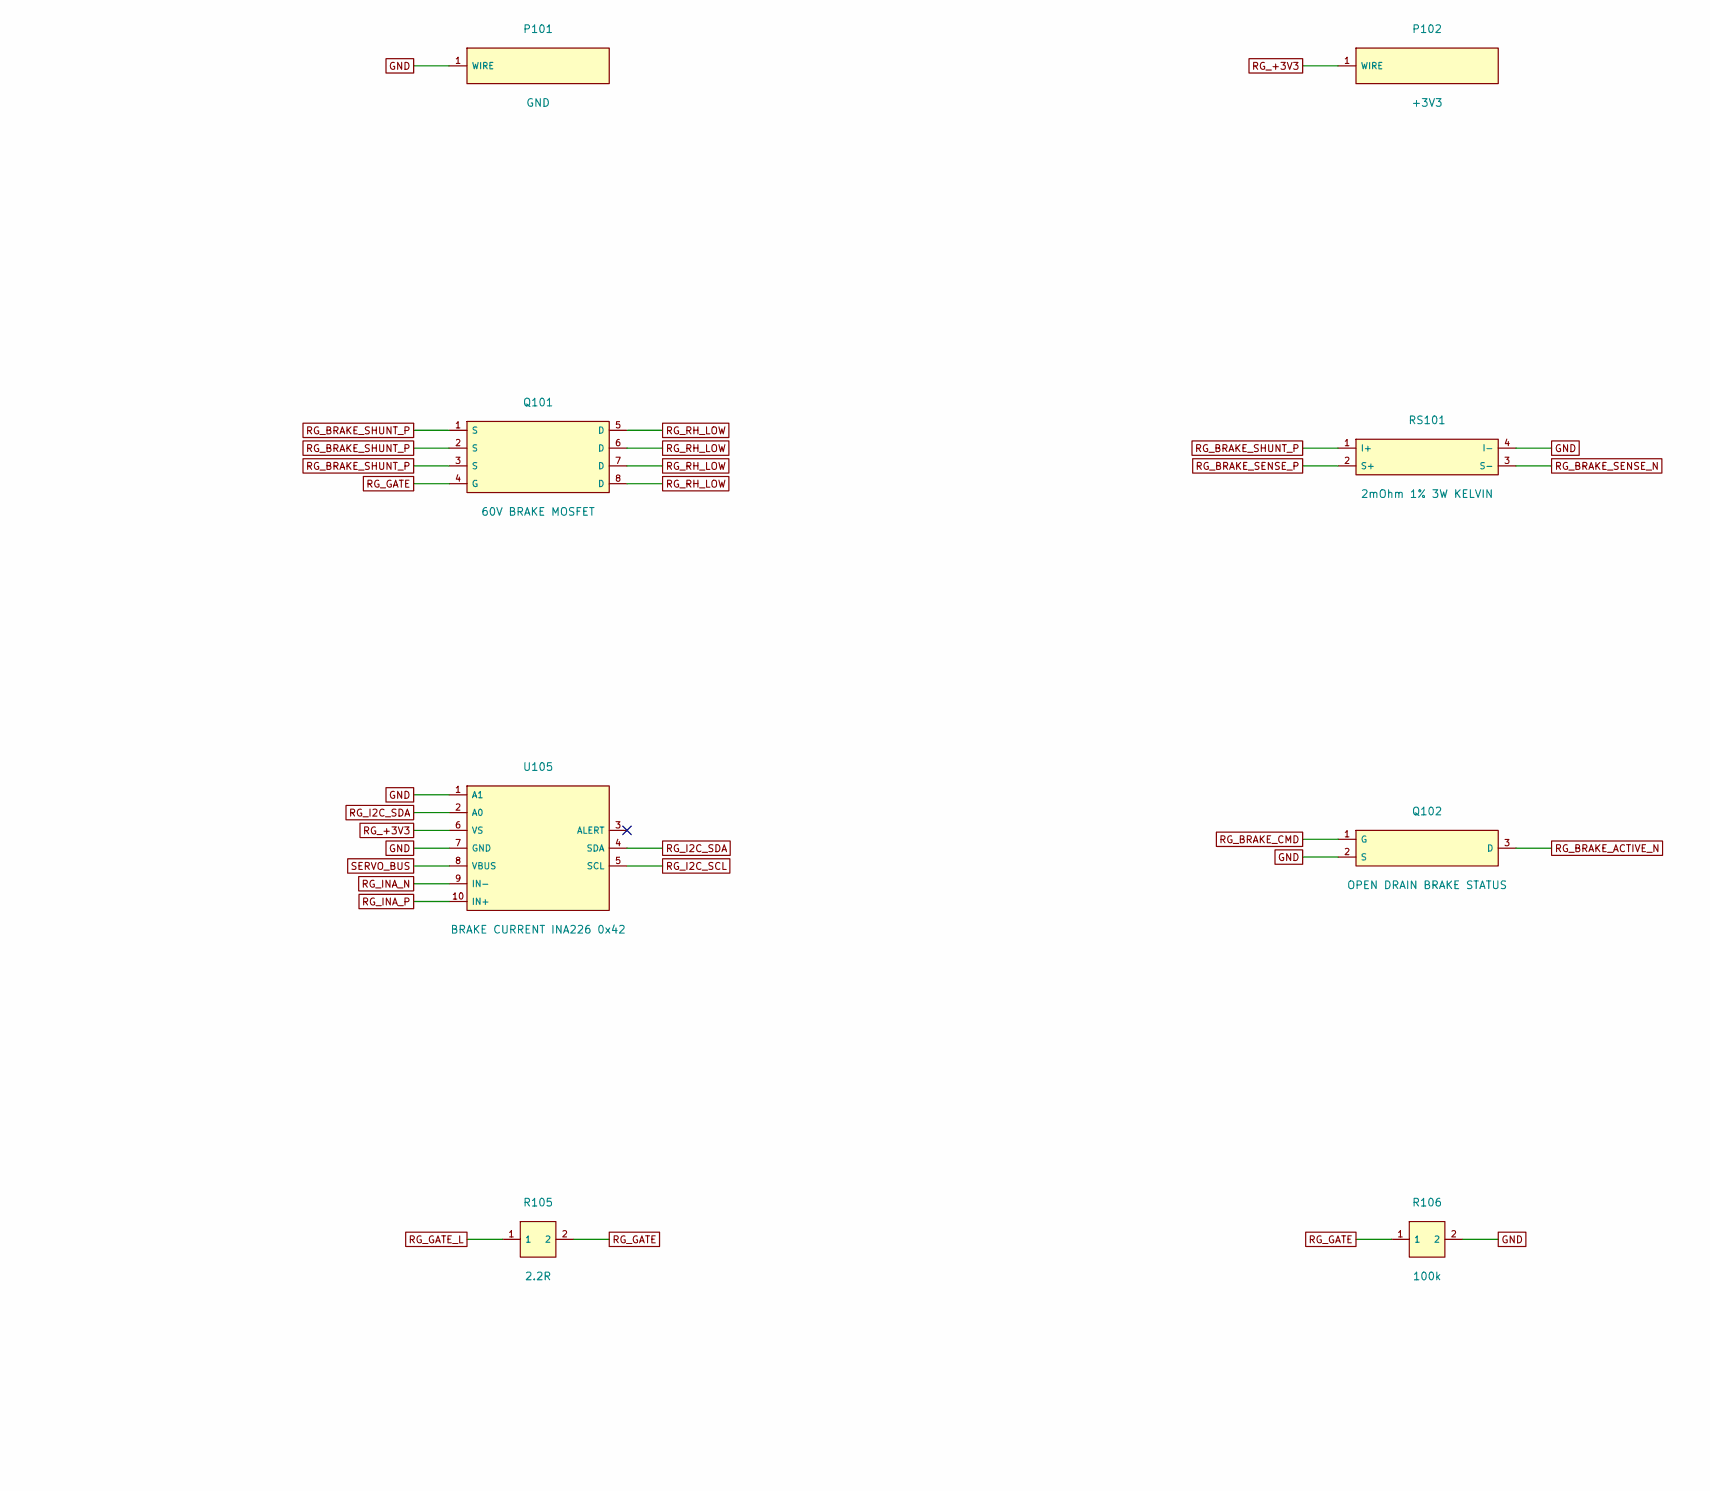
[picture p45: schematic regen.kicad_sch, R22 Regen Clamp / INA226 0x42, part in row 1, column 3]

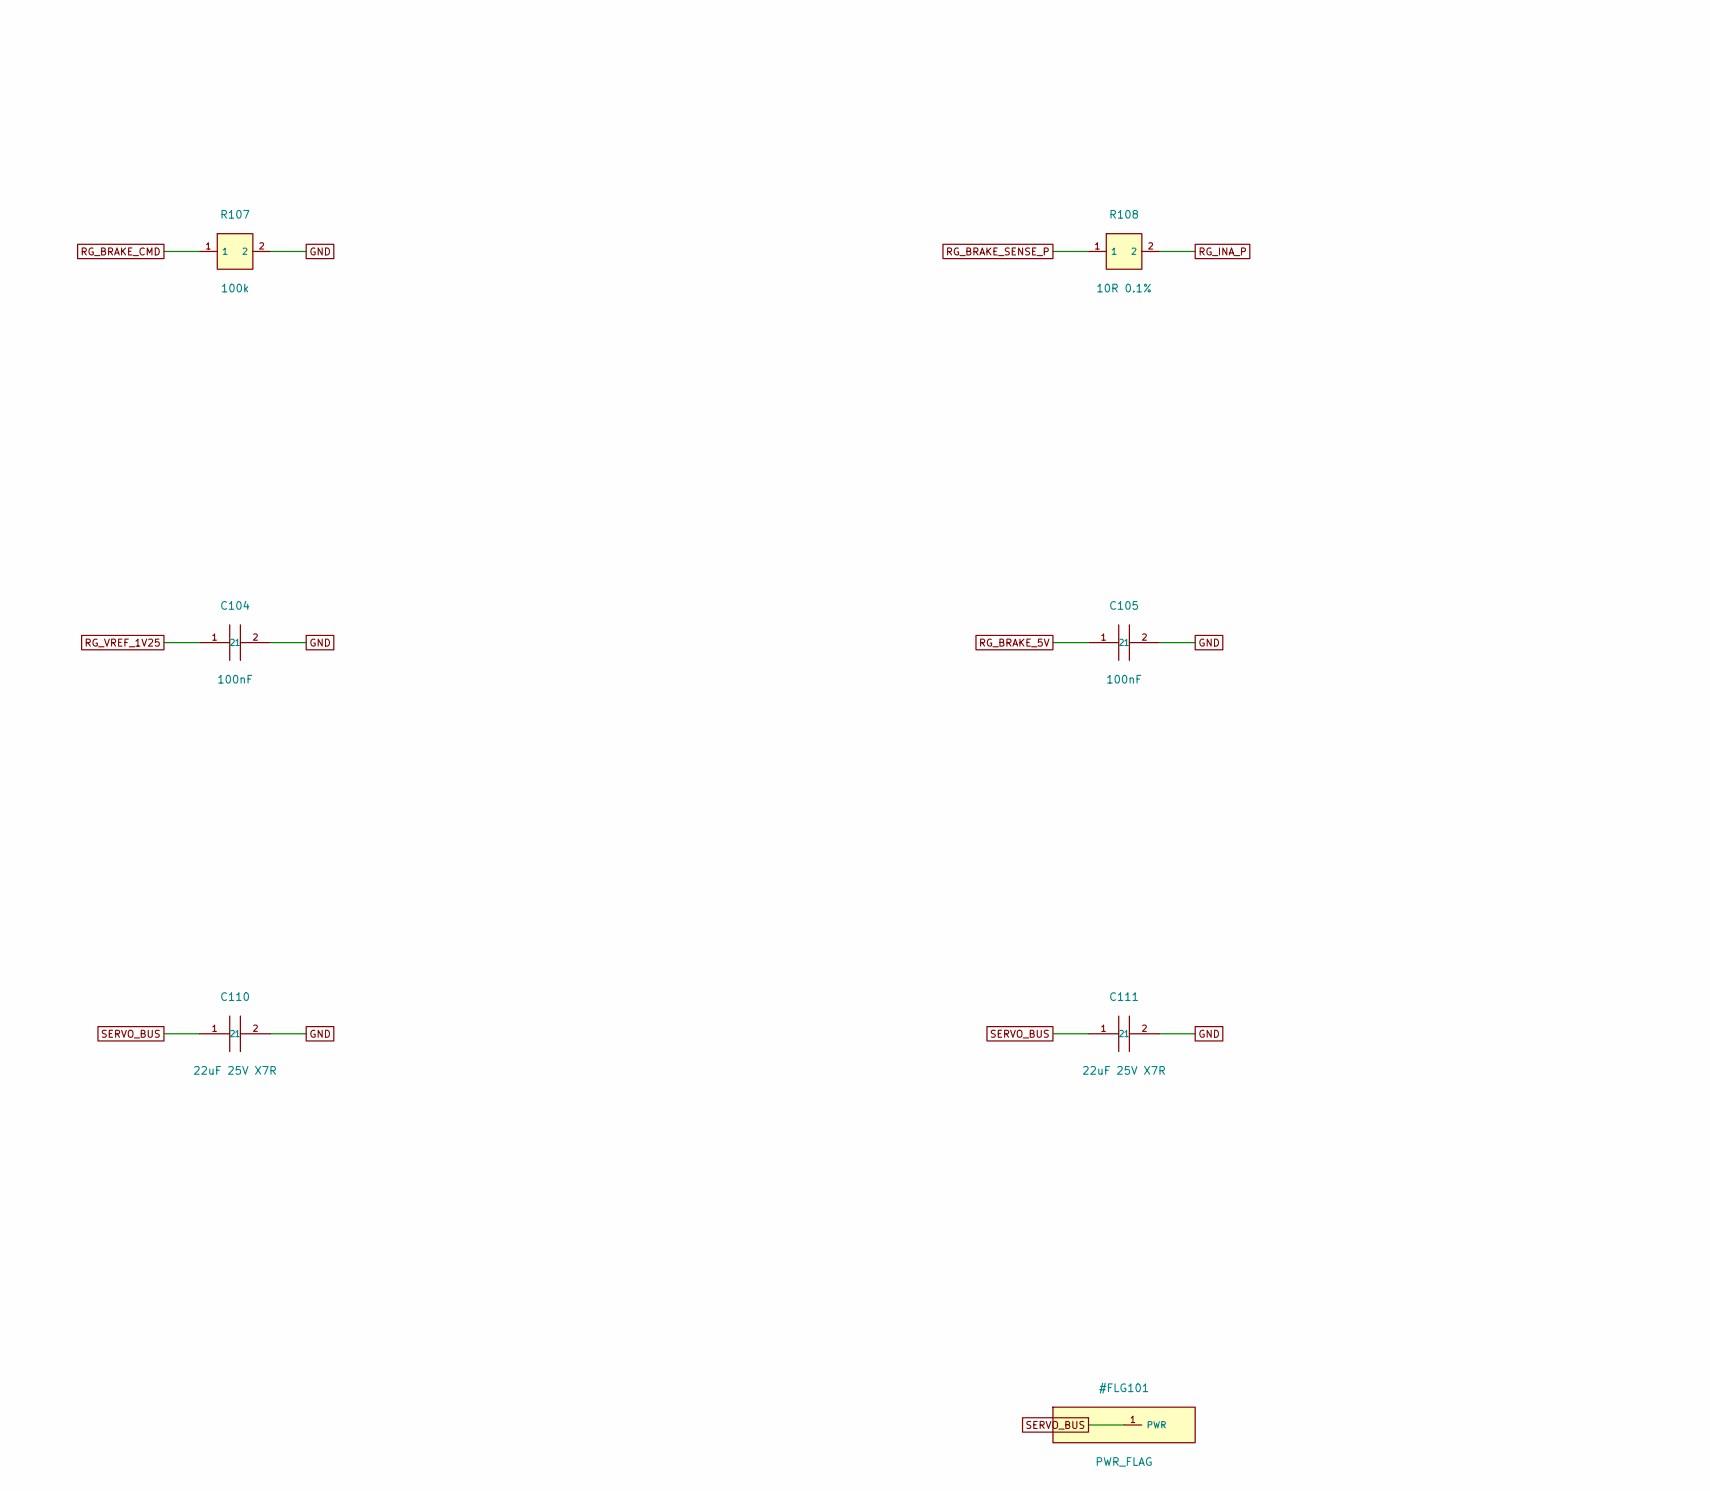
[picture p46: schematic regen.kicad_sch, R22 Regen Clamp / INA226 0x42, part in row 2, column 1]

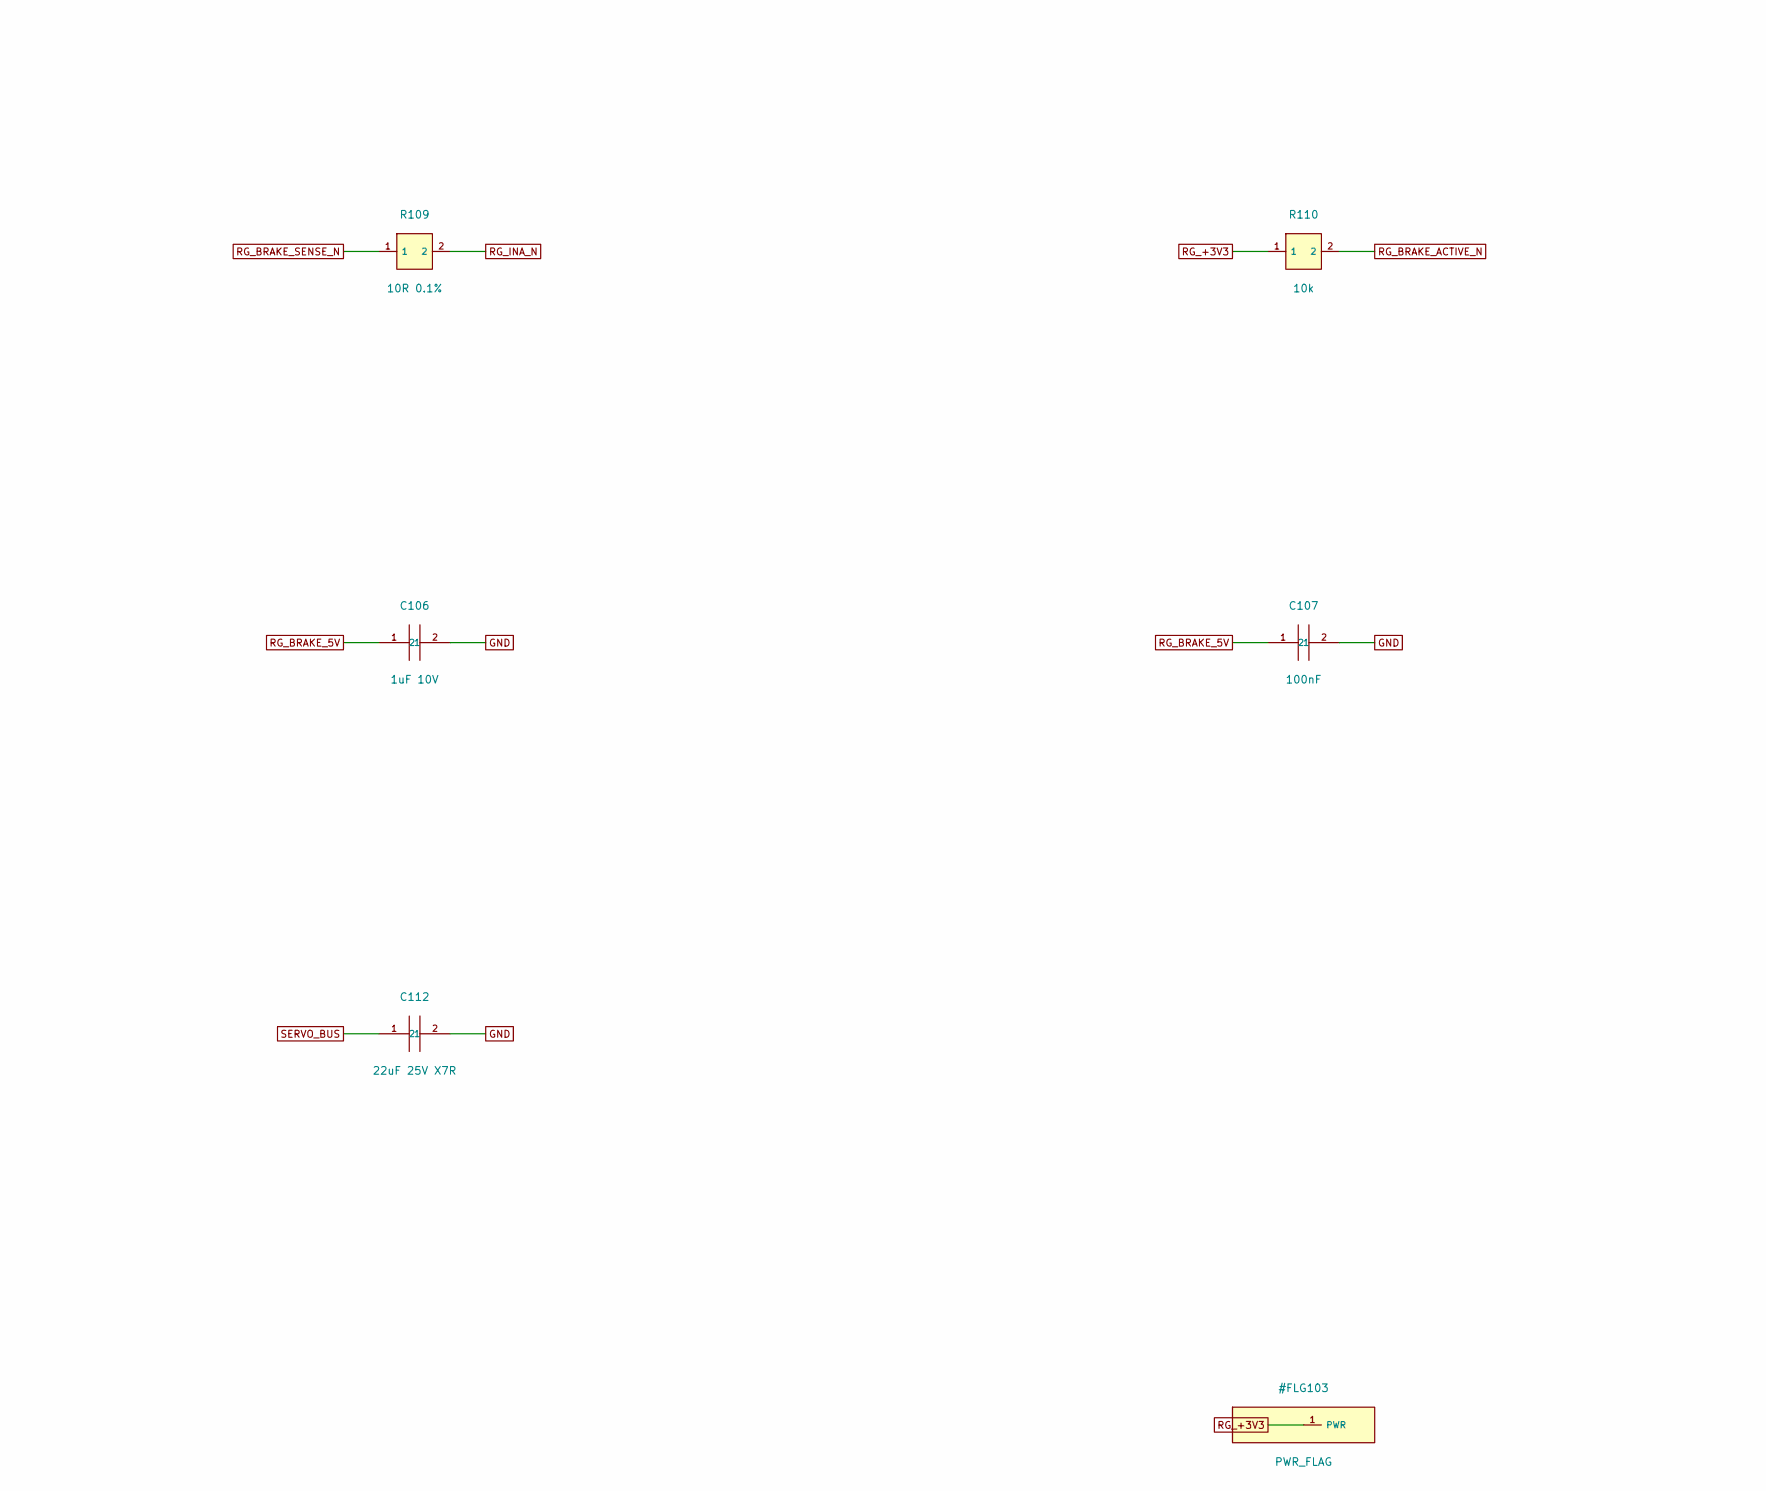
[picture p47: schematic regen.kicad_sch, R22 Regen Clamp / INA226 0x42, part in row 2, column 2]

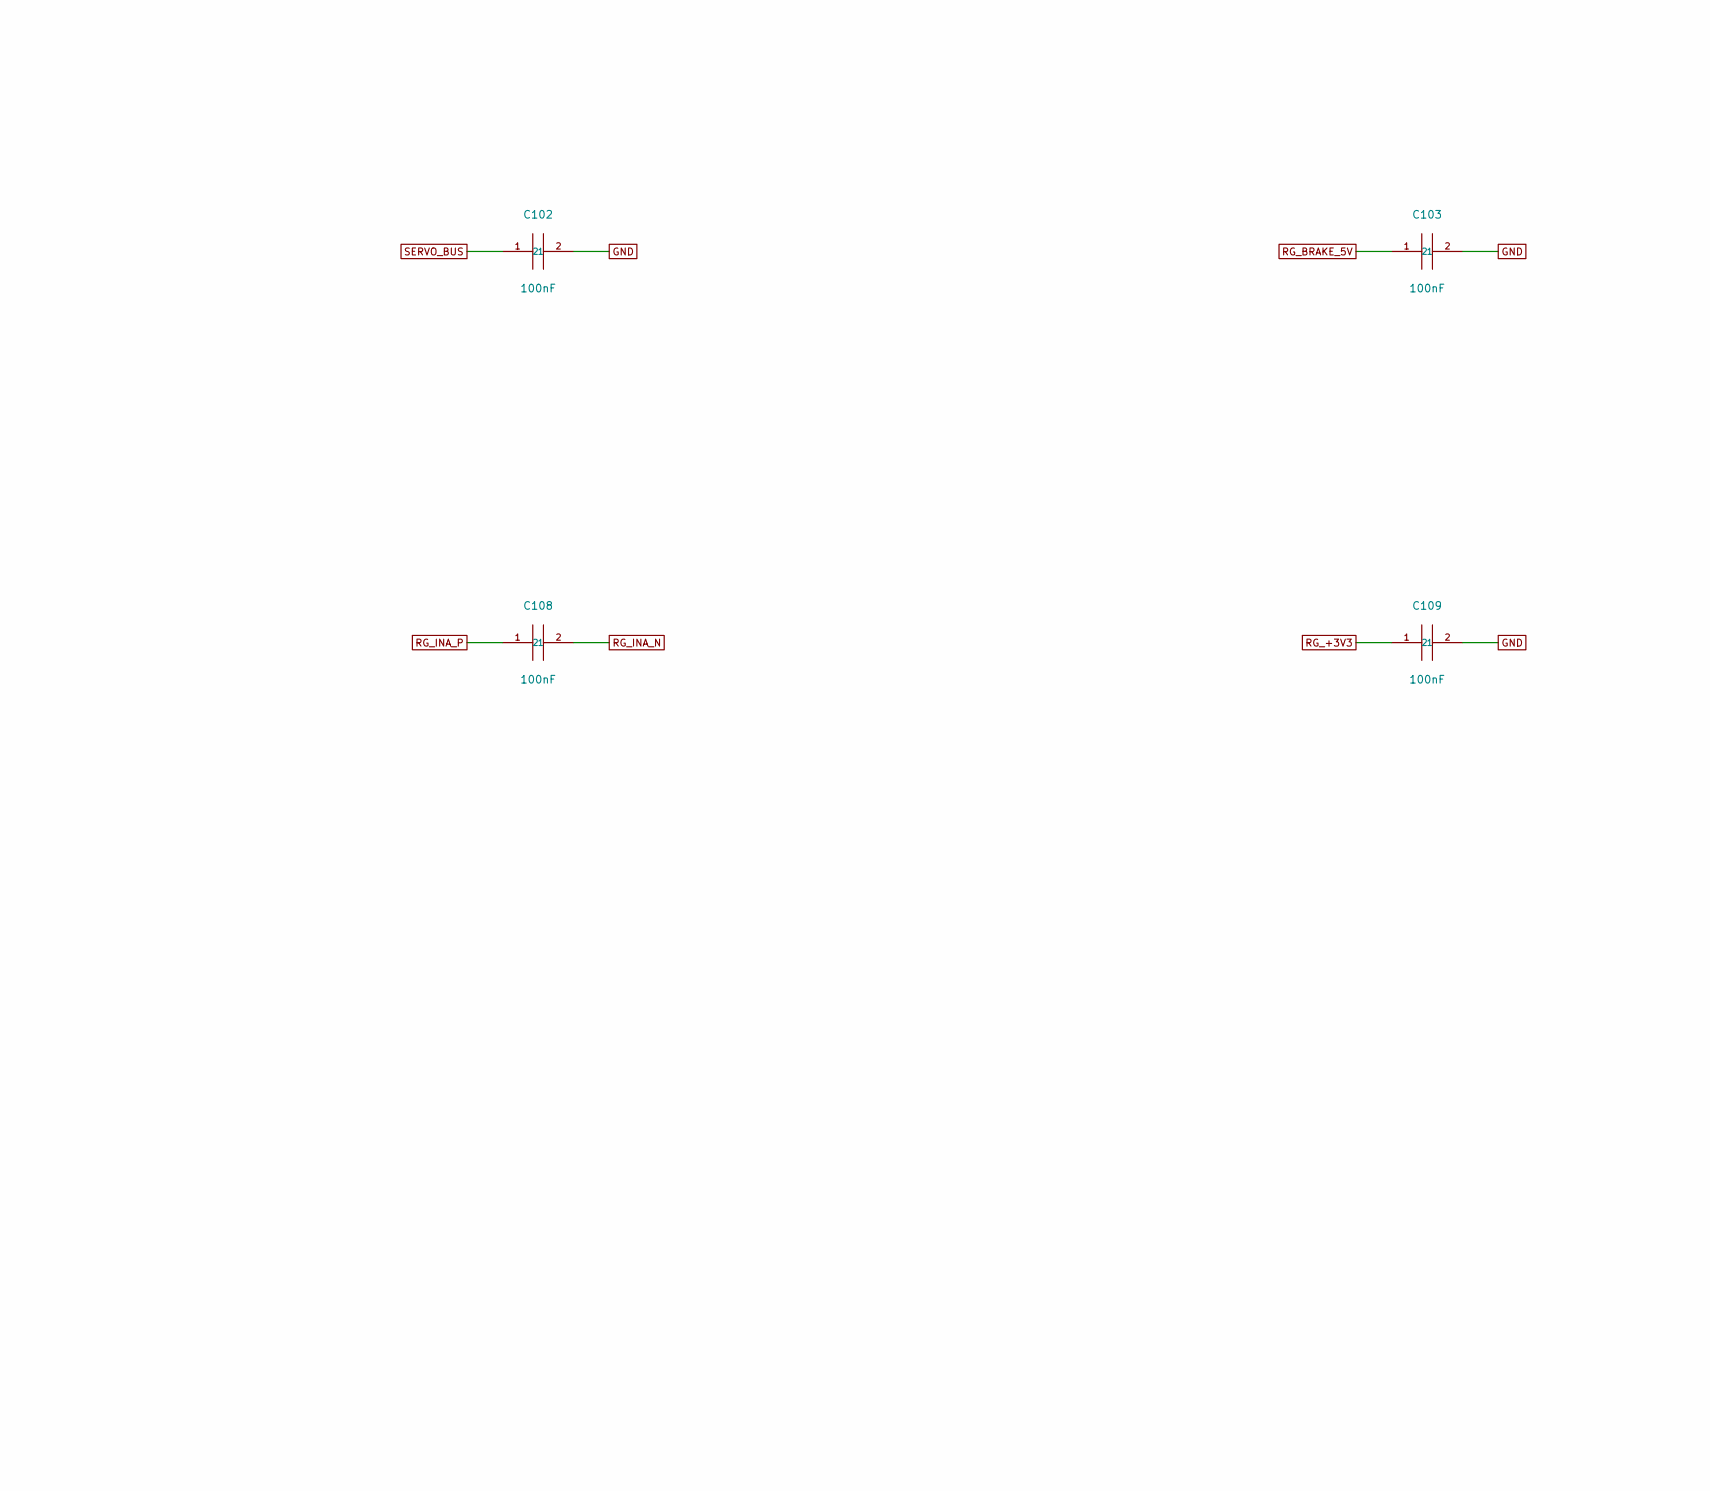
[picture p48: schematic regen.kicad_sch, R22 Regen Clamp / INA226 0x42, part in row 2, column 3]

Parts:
C101: 2200uF 16V LOW ESR; CP_EEUFR1C222_Horizontal_Clip; MPN EEUFR1C222
C102, C103, C104, C105, C107, C108, C109: 100nF; C_0603_1608Metric; MPN GRM188R71H104KA93D
C106: 1uF 10V; C_0603_1608Metric; MPN GRM188R71A105KA61D
C110, C111, C112: 22uF 25V X7R; C_1210_3225Metric; MPN GRM32ER71E226KE15L
P101: GND; WireSignal_0p5mm; MPN SOLDER AWG28 PIGTAIL
P102: +3V3; WireSignal_0p5mm; MPN SOLDER AWG28 PIGTAIL
P103: I2C_SDA; WireSignal_0p5mm; MPN SOLDER AWG28 PIGTAIL
P104: I2C_SCL; WireSignal_0p5mm; MPN SOLDER AWG28 PIGTAIL
P105: BRAKE_ACTIVE_N; WireSignal_0p5mm; MPN SOLDER AWG28 PIGTAIL
Q101: 60V BRAKE MOSFET; CSD18540Q5B_DNK; MPN CSD18540Q5B
Q102: OPEN DRAIN BRAKE STATUS; SOT-23; MPN BSS138
R101: 80.6k 0.1%; R_0603_1608Metric; MPN RT0603BRD0780K6L
R102: 10.0k 0.1%; R_0603_1608Metric; MPN RT0603BRD0710KL
R103: 2.20M 0.1%; R_0603_1608Metric; MPN RT0603BRD072M2L
R104: 4.7R; R_0603_1608Metric; MPN ERJ-3EKF4R7V
R105: 2.2R; R_0603_1608Metric; MPN ERJ-3EKF2R2V
R106, R107: 100k; R_0603_1608Metric; MPN ERJ-3EKF1003V
R108, R109: 10R 0.1%; R_0603_1608Metric; MPN RT0603BRD0710RL
R110: 10k; R_0603_1608Metric; MPN ERJ-3EKF1002V
RS101: 2mOhm 1% 3W KELVIN; WSL2726_Kelvin; MPN WSL27262L000FEA
U101: BUS POWERED 5V LDO; SOT-23; MPN TLV76050DBZR
U102: 1.25V PRECISION REF; SOT-23; MPN REF3312AIDBZR
U103: REGEN HYSTERETIC COMPARATOR; SOT-23-5; MPN TLV3201AIDBVR
U104: GATE SOURCE SINK DRIVER; SOT-23-6; MPN UCC27511DBVR
U105: BRAKE CURRENT INA226 0x42; TI_DGS0010A_1p45x0p30; MPN INA226AIDGSR
W103: SERVO_BUS; WirePad_2p4mm_6mm; MPN SOLDER AWG16
W104: RH_LOW; WirePad_2p4mm_6mm; MPN SOLDER AWG16

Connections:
GND: C101.2, C102.2, C103.2, C104.2, C105.2, C106.2, C107.2, C109.2, C110.2, C111.2, C112.2, P101.1, Q102.2 (S), R102.2, R106.2, R107.2, RS101.4 (I-), U101.3 (GND), U102.3 (GND), U103.2 (GND), U104.4 (GND), U104.5 (IN-), U105.1 (A1), U105.7 (GND); also elsewhere on the board
RG_+3V3: C109.1, P102.1, R110.1, U105.6 (VS)
RG_BRAKE_5V: C103.1, C105.1, C106.1, C107.1, U101.1 (OUT), U102.1 (IN), U103.5 (VCC), U104.1 (VDD)
RG_BRAKE_ACTIVE_N: P105.1, Q102.3 (D), R110.2
RG_BRAKE_CMD: Q102.1 (G), R103.1, R107.1, U103.1 (OUT), U104.6 (IN+)
RG_BRAKE_SENSE_N: R109.1, RS101.3 (S-)
RG_BRAKE_SENSE_P: R108.1, RS101.2 (S+)
RG_BRAKE_SHUNT_P: Q101.1 (S), Q101.2 (S), Q101.3 (S), RS101.1 (I+)
RG_GATE: Q101.4 (G), R104.2, R105.2, R106.1
RG_GATE_H: R104.1, U104.2 (OUTH)
RG_GATE_L: R105.1, U104.3 (OUTL)
RG_I2C_SCL: P104.1, U105.5 (SCL)
RG_I2C_SDA: P103.1, U105.2 (A0), U105.4 (SDA)
RG_INA_N: C108.2, R109.2, U105.9 (IN-)
RG_INA_P: C108.1, R108.2, U105.10 (IN+)
RG_REGEN_DIV: R101.2, R102.1, R103.2, U103.3 (IN+)
RG_RH_LOW: Q101.5 (D), Q101.6 (D), Q101.7 (D), Q101.8 (D), W104.1
RG_VREF_1V25: C104.1, U102.2 (OUT), U103.4 (IN-)
SERVO_BUS: C101.1, C102.1, C110.1, C111.1, C112.1, R101.1, U101.2 (IN), U105.8 (VBUS), W103.1; also elsewhere on the board

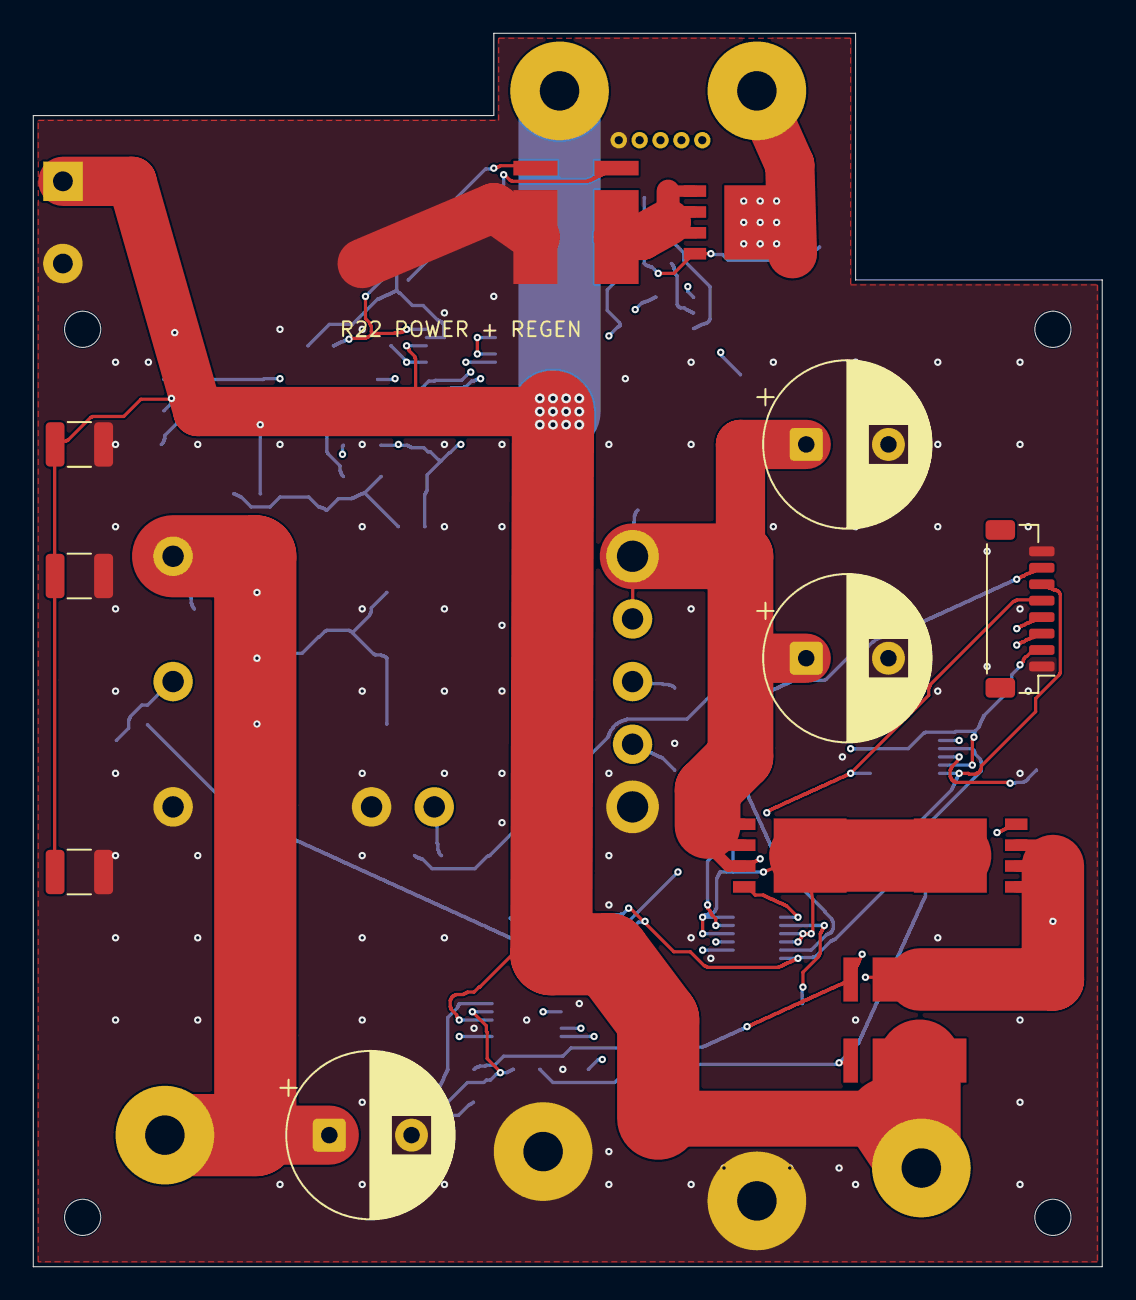
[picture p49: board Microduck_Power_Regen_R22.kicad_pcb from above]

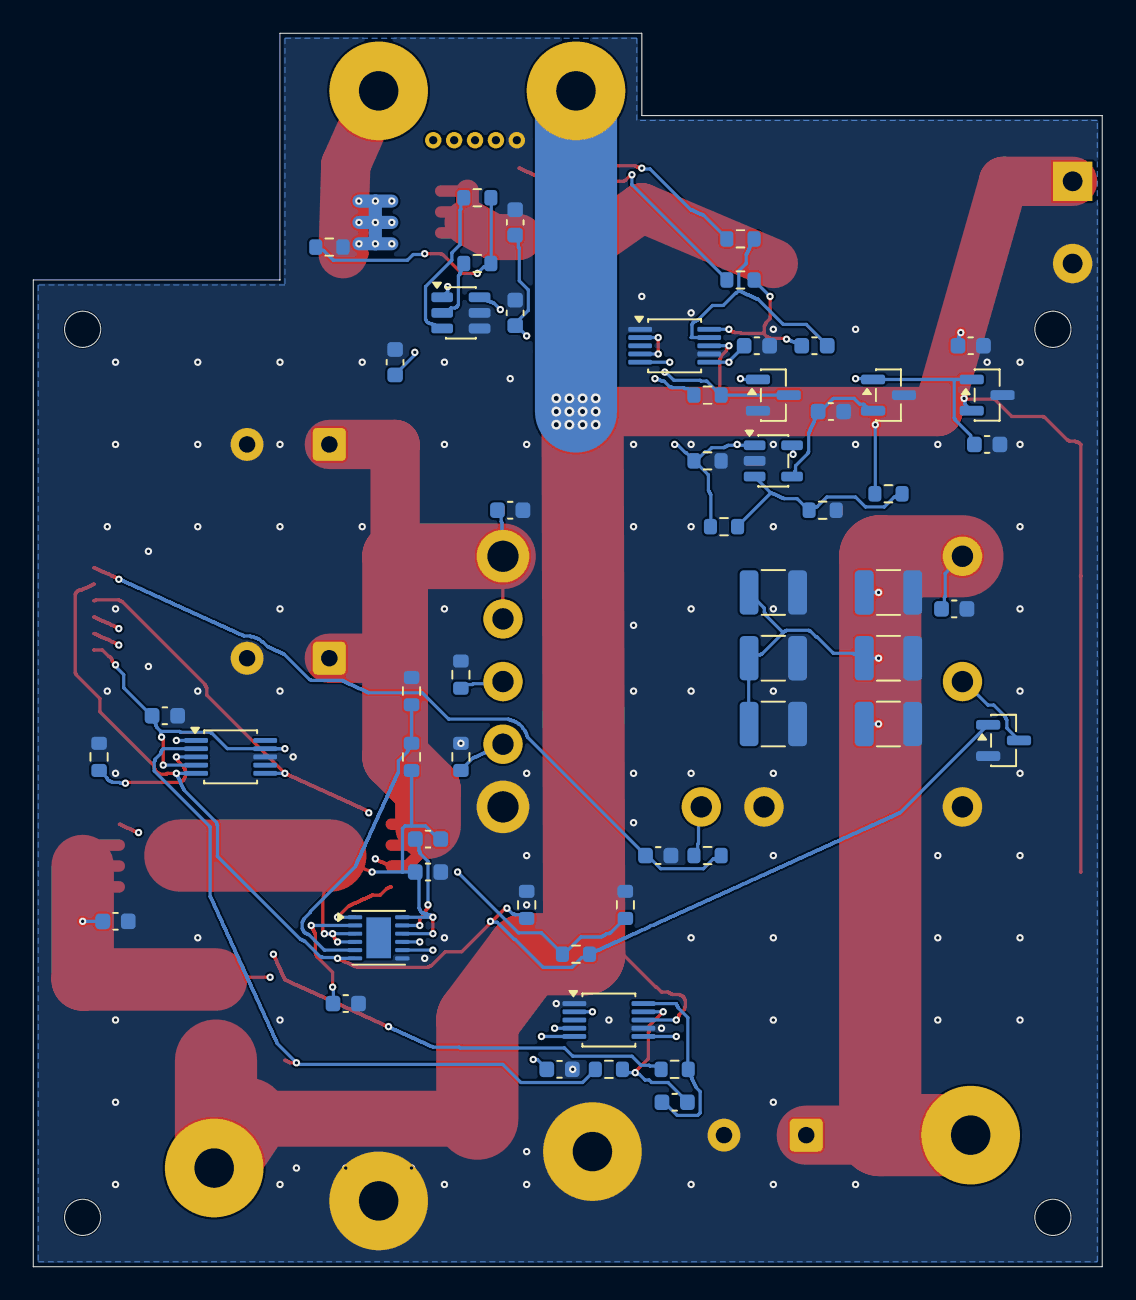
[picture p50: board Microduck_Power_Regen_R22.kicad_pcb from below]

Board: 4 copper layers, 65.0 x 75.0 mm, 84 parts (55 on the bottom side), 42 nets.

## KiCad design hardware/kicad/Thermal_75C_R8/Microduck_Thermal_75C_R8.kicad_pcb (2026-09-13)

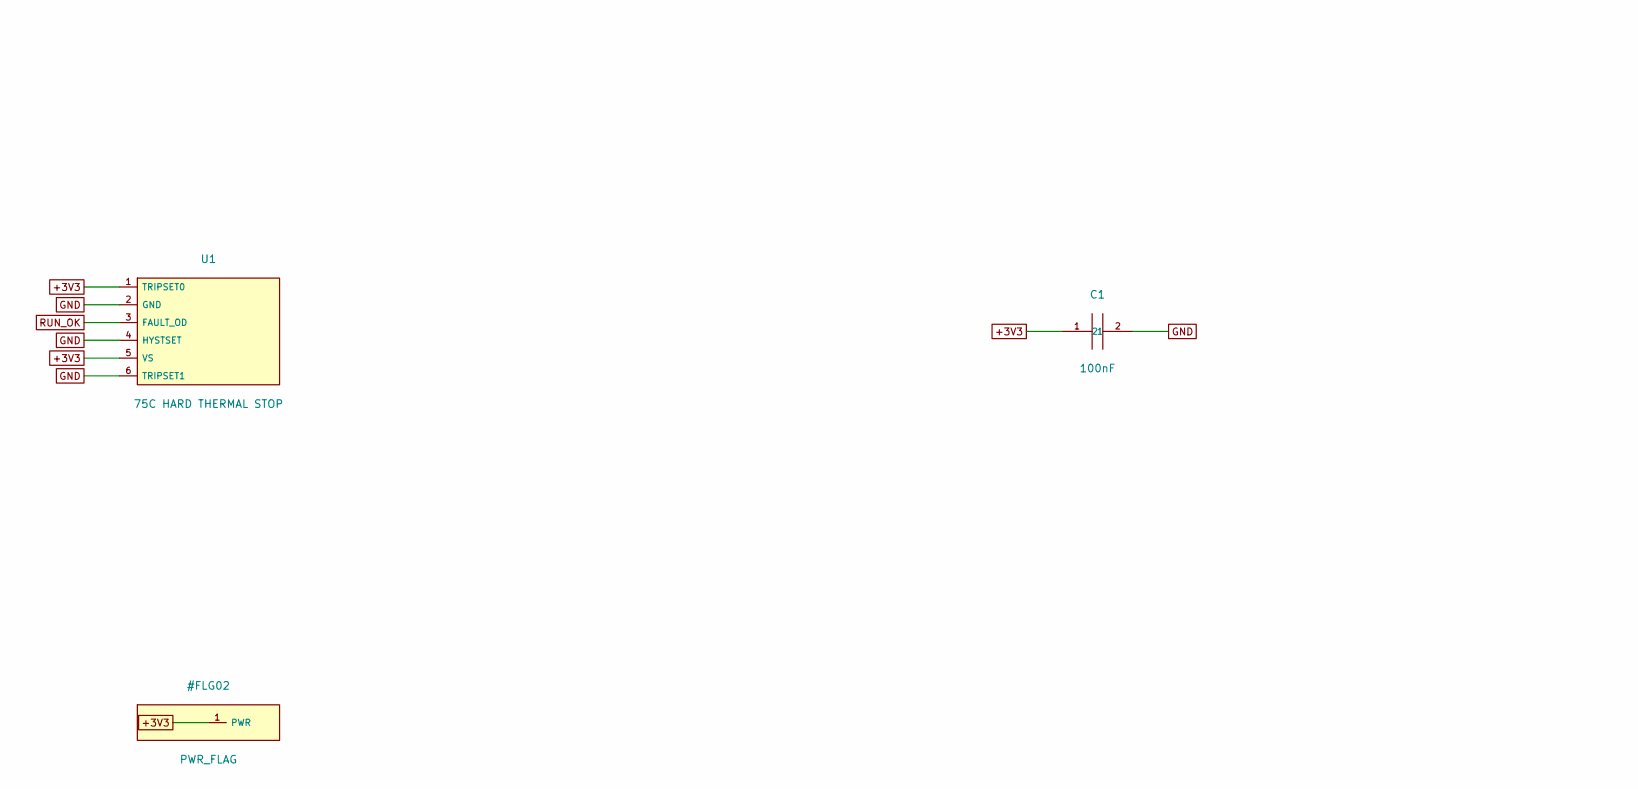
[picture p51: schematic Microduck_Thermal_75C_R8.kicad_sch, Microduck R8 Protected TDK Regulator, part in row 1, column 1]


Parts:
C1: 100nF; C_0603_1608Metric; MPN GRM188R71H104KA93D
H1, H2: M2 NPTH; MountingHole_2.2mm_M2; MPN NO PART
J1: 3V3 / FAULT OD; JST_SH_SM03B-SRSS-TB_1x03-1MP_P1.00mm_Horizontal; MPN SM03B-SRSS-TB(LF)(SN)
U1: 75C HARD THERMAL STOP; SOT-563; MPN TMP302BDRLR

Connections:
+3V3: C1.1, J1.2 (3V3), U1.1 (TRIPSET0), U1.5 (VS)
GND: C1.2, J1.1 (GND), U1.2 (GND), U1.4 (HYSTSET), U1.6 (TRIPSET1)
RUN_OK: J1.3 (RUN_OK), U1.3 (FAULT_OD)

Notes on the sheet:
R8 CONTROLLED PROTOTYPE / 4S -> 10.8V / ACTIVE CURRENT LATCH + REVERSE BLOCK / SOURCE DATASHEETS REQUIRED
J1.5 RUN_REQ defaults LOW. OC latches via INA300; clear only while RUN_REQ LOW. Brake board mandatory on SERVO_BUS.
TDK ITRIM tolerance is TYPICAL; INA300 provides independent trip. 10A copper target requires physical thermal qualification.



Board: 2 copper layers, 16.0 x 12.0 mm, 5 parts (2 on the bottom side), 3 nets.

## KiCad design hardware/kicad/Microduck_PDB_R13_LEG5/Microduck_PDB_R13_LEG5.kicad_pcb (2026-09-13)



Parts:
F1, F2, F3, F4, F5: 3A VERY FAST; Fuse_Littelfuse_448; MPN 0448003.MR
H1, H2: M2.5 NPTH; MountingHole_2.7mm_M2.5; MPN NO PART
J1: PORT 1; JST_EH_S3B-EH_1x03_P2.50mm_Horizontal; MPN S3B-EH(LF)(SN)
J2: PORT 2; JST_EH_S3B-EH_1x03_P2.50mm_Horizontal; MPN S3B-EH(LF)(SN)
J3: PORT 3; JST_EH_S3B-EH_1x03_P2.50mm_Horizontal; MPN S3B-EH(LF)(SN)
J4: PORT 4; JST_EH_S3B-EH_1x03_P2.50mm_Horizontal; MPN S3B-EH(LF)(SN)
J5: PORT 5; JST_EH_S3B-EH_1x03_P2.50mm_Horizontal; MPN S3B-EH(LF)(SN)
J6: GND/DATA IN-OUT; JST_SH_SM04B-SRSS-TB_1x04-1MP_P1.00mm_Horizontal; MPN SM04B-SRSS-TB(LF)(SN)
W1: 10.8V AWG16; WirePad_2p4mm_6mm; MPN WIRE55A0111-16-2
W2: GND AWG16; WirePad_2p4mm_6mm; MPN WIRE55A0111-16-0

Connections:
DXL_DATA: J1.3 (DATA), J2.3 (DATA), J3.3 (DATA), J4.3 (DATA), J5.3 (DATA), J6.2 (DATA_IN), J6.4 (DATA_OUT)
GND: J1.1 (GND), J2.1 (GND), J3.1 (GND), J4.1 (GND), J5.1 (GND), J6.1 (GND_IN), J6.3 (GND_OUT), W2.1
VIN_MAIN: F1.1, F2.1, F3.1, F4.1, F5.1, W1.1
V_SERVO_1: F1.2, J1.2 (VDD)
V_SERVO_2: F2.2, J2.2 (VDD)
V_SERVO_3: F3.2, J3.2 (VDD)
V_SERVO_4: F4.2, J4.2 (VDD)
V_SERVO_5: F5.2, J5.2 (VDD)

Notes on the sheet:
R13 LEG5 - FUSED SERVO DISTRIBUTION / NOT A REGULATOR
10.8V / AWG16; 10A path target. Upstream trip approx11.7A static worst case, NOT instantaneous12A ceiling.
Each port <=2A continuous target. 3A fuse is NOT an active current limiter.
Jx EH:1=GND 2=individual fused positive 3=TTL DATA. Never bridge branch positive.
J6:2=DATA-IN 4=DATA-OUT. Harness pins1/3 EMPTY+SEALED; PCB GND test only.
LEG5 x2 plus HEAD3 x1:13 protected branches cover12XM430 +3XC330 motors.
2-layer70um copper per side / finished1.6mm. Load, thermal, SI and mechanical first article pending.


Board: 2 copper layers, 40.0 x 36.0 mm, 15 parts (0 on the bottom side), 8 nets.

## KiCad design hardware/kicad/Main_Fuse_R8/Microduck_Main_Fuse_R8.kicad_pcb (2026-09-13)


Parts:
F1: MAIN 15A MINI; Keystone_3549_2_Horizontal; MPN 3549-2 + 0297015.WXNV
H1, H2: M2 NPTH; MountingHole_2.2mm_M2; MPN NO PART
W1: CELL4; Wire_SMD5; MPN AWG16 solder with independent clamp
W2: BAT_FUSED; Wire_SMD5; MPN AWG16 solder with independent clamp

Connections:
BAT_FUSED: F1.2 (FUSED OUT), W2.1
CELL4: F1.1 (CELL4 IN), W1.1

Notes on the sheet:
CELL4 positive -> W1 -> 0297015.WXNV 15A32VDC in Keystone3549-2 -> W2 BAT_FUSED
Install close to battery positive, source wire target<=50mm; isolated fixed harness; not Entry logic2A fuse.
Holder20A is contact rating; blade15A is time-current fuse, not instantaneous15A limit. Only replace with battery disconnected.

Board: 2 copper layers, 5 parts (2 on the bottom side), 2 nets, no tracks yet.

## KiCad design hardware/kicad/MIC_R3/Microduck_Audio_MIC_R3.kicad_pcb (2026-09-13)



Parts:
C1, C4, C5: 100nF X7R; C_0603_1608Metric; MPN GRM188R71C104KA01D
C2, C3: 1uF 10V X7R; C_0603_1608Metric; MPN GRM188R71A105KA61D
H1, H2: M2 NPTH; MountingHole_2.2mm_M2; MPN NO PART
J1: SH5; JST_SH_SM05B-SRSS-TB_1x05-1MP_P1.00mm_Horizontal; MPN SM05B-SRSS-TB(LF)(SN)
R1: 100k SD PULLDOWN; R_0603_1608Metric; MPN RC0603FR-07100KL
U1: T5848 LEFT HQ; T5848_LGA8_BottomPort; MPN MMICT5848-00-012
U2: TXU0204PWR; TSSOP-14_4.4x5mm_P0.65mm; MPN TXU0204PWR
U3: 1.8V LDO; SOT-23-5; MPN TLV75518PDBVR

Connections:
+1V8: C1.1, C3.1, C5.1, U1.7 (VDD), U2.8 (OE), U2.14 (VCCB), U3.5 (OUT)
+3V3: C2.1, C4.1, J1.2 (3V3_INPUT), U2.1 (VCCA), U3.1 (IN), U3.3 (EN)
BCLK_1V8: U1.6 (SCK), U2.13 (B1Y)
GND: C1.2, C2.2, C3.2, C4.2, C5.2, J1.1 (GND), R1.2, U1.2 (LR), U1.3 (GND), U2.7 (GND), U2.10 (B4), U3.2 (GND)
I2S_BCLK: J1.3 (BCLK), U2.2 (A1)
I2S_RX: J1.5 (RX), U2.4 (A3Y)
I2S_WS: J1.4 (WS), U2.3 (A2)
SD_1V8: R1.1, U1.8 (SD), U2.11 (B3)
WS_1V8: U1.1 (WS), U2.12 (B2Y)

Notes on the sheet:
R3 CONTROLLED PROTOTYPE / SEE PIN-TO-PIN HARNESS AND POWER BUDGET
48kHz I2S / RK MASTER / 32-bit stereo slots / BCLK 3.072MHz / SD_MODE DEFAULT OFF



Board: 2 copper layers, 20.0 x 14.0 mm, 12 parts (3 on the bottom side), 9 nets.

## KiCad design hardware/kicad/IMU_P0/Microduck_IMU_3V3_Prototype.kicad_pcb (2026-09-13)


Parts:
C1, C2: 100nF; C_0603_1608Metric; MPN CC0603KRX7R9BB104
C3: 2.2uF; C_0603_1608Metric; MPN GRM188R71A225KE15D
H1, H2: M2_NPTH; MountingHole_2.2mm_M2; MPN 2.2 mm NPTH
J1: Qwiic_3V3_ONLY; JST_SH_SM04B-SRSS-TB_1x04-1MP_P1.00mm_Horizontal; MPN SM04B-SRSS-TB(LF)(SN)
J2: DEBUG_3V3; PinHeader_1x04_P2.54mm_Vertical; MPN 2.54mm 1x04 TH header; optional; not fitted
R1, R2: 4.7k; R_0603_1608Metric; MPN RC0603FR-074K7L
TP1: INT1; TestPoint_Pad_D1.0mm; MPN PCB test point 1 mm
TP2: INT2; TestPoint_Pad_D1.0mm; MPN PCB test point 1 mm
U1: LSM6DSV16XTR; LSM6DSV16X_LGA14; MPN LSM6DSV16XTR

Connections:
+3V3: C1.1, C2.1, C3.1, J1.2 (3V3), J2.2 (3V3), R1.1, R2.1, U1.5 (VDDIO), U1.8 (VDD), U1.12 (CS)
GND: C1.2, C2.2, C3.2, J1.1 (GND), J2.1 (GND), U1.1 (SDO/SA0), U1.2 (SDx_Mode1_GND), U1.3 (SCx_Mode1_GND), U1.6 (GND), U1.7 (GND)
INT1: TP1.1, U1.4 (INT1)
INT2: TP2.1, U1.9 (INT2)
SCL: J1.4 (SCL), J2.4 (SCL), R2.2, U1.13 (SCL)
SDA: J1.3 (SDA), J2.3 (SDA), R1.2, U1.14 (SDA)

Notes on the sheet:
MICRODUCK / 3.3 V I2C IMU PROTOTYPE
Mode 1 / 7-bit I2C address 0x6A / LSM6DSV16XTR
3.3 V ONLY. No regulator and no level translator.
R1/R2 fitted by default; remove if host already provides pull-ups.
J2 optional DNP. INT1/INT2 are accessible test points.
Pins 2/3 tied GND; pins 10/11 intentionally NC.
Prototype: assembly inspection and bench validation required.
C1 at VDDIO, C2 at VDD; C3 at the power input.


Board: 2 copper layers, 24.0 x 18.0 mm, 12 parts (0 on the bottom side), 6 nets.

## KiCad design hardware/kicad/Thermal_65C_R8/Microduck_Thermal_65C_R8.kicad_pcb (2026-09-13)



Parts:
C1: 100nF; C_0603_1608Metric; MPN GRM188R71H104KA93D
H1, H2: M2 NPTH; MountingHole_2.2mm_M2; MPN NO PART
J1: 3V3 / FAULT OD; JST_SH_SM03B-SRSS-TB_1x03-1MP_P1.00mm_Horizontal; MPN SM03B-SRSS-TB(LF)(SN)
U1: 65C HARD THERMAL STOP; SOT-563; MPN TMP302ADRLR

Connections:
+3V3: C1.1, J1.2 (3V3), U1.1 (TRIPSET0), U1.5 (VS), U1.6 (TRIPSET1)
GND: C1.2, J1.1 (GND), U1.2 (GND), U1.4 (HYSTSET)
RUN_OK: J1.3 (RUN_OK), U1.3 (FAULT_OD)

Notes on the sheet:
R8 CONTROLLED PROTOTYPE / 4S -> 10.8V / ACTIVE CURRENT LATCH + REVERSE BLOCK / SOURCE DATASHEETS REQUIRED
J1.5 RUN_REQ defaults LOW. OC latches via INA300; clear only while RUN_REQ LOW. Brake board mandatory on SERVO_BUS.
TDK ITRIM tolerance is TYPICAL; INA300 provides independent trip. 10A copper target requires physical thermal qualification.



Board: 2 copper layers, 16.0 x 12.0 mm, 5 parts (2 on the bottom side), 3 nets.

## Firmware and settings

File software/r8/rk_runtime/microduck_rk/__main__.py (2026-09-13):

"""Explicit commissioning, diagnostics, command lease, and 50 Hz control CLI."""
import argparse
import json
import math
import os
from pathlib import Path
import signal
import sys
import time
from .contract import Calibration,observation,action_targets
from .safety import Guard,read_command,mouth_step,check_joint_currents
from .telemetry import publish as publish_telemetry
from .motion_context import MotionContextGuard
from microduck_interaction.executor import CommandWriter
from microduck_interaction.schema import ROBOT_PROFILE


def hardware_args(p):
    p.add_argument('--calibration',required=True)
    p.add_argument('--serial',default='/dev/serial/by-id/REPLACE_WITH_U2D2_ID')
    p.add_argument('--i2c',help='optional override must equal calibrated CM4 sensor I2C device')
    p.add_argument('--power-config',required=True,help='measured CM4 power calibration JSON')
    p.add_argument('--address',type=lambda s:int(s,0),default=0x6a)


def run(args):
    if Path(args.stop_file).exists(): raise RuntimeError('STOP file present; hardware startup refused')
    if isinstance(args.seconds,bool) or not math.isfinite(args.seconds) or not 0<args.seconds<=7200:raise ValueError('run duration must be finite, positive, at most7200s')
    from .imu import LinuxI2c,Lsm6dsv16x,ImuWorker
    from .dynamixel import Dynamixels
    from .policy import Policy
    from .power import PowerConfig,PowerSystem
    # All gates before opening a servo port. Template cannot arm.
    cal=Calibration.load(args.calibration,motion=True)
    if args.robot_profile!=cal.data['robot']:raise ValueError('R8 telemetry/action robot profile mismatch')
    if not args.arm: raise ValueError('run requires explicit --arm after commissioning')
    power_config=PowerConfig.load(args.power_config)
    if power_config.sha256!=cal.data.get('power_configuration_sha256'):raise ValueError('power configuration SHA differs from calibrated robot')
    if args.address!=0x6a or (args.i2c and args.i2c!=power_config.data['i2c_device']):raise ValueError('CM4 sensor bus/address differs from power contract')
    context=MotionContextGuard(cal.home,getattr(args,'motion_context','head_home_locked'),getattr(args,'confirm_supported_double',False))
    policy=Policy(args.policy,cal,args.manifest,context.mode)
    bench=policy.benchmark()
    if bench['p99_ms']>8: raise RuntimeError(f'CPU policy p99 exceeds 8ms preflight budget: {bench}')
    bus=None;motors=None;log=None;imu=None;power=None
    last_measured=None;last_sent=None
    def stop_signal(*_): raise KeyboardInterrupt
    signal.signal(signal.SIGTERM,stop_signal); signal.signal(signal.SIGINT,stop_signal)
    try:
        power=PowerSystem(power_config);power.start()
        bus=LinuxI2c(power_config.data['i2c_device'],args.address)
        imu=ImuWorker(Lsm6dsv16x(bus,cal.data['imu_sensor_to_trunk_wxyz']));imu.start();imu.wait_ready()
        power.enable();time.sleep(.2) # Rail established before bounded servo boot/verification; torque still off.
        motors=Dynamixels(args.serial,cal); motors.prepare_enable()
        actual=motors.read(); state=imu.read(); cmd,mouth,lease=read_command(args.command)
        check_joint_currents(actual['current_ma'],cal)
        guard=Guard(cal.data);guard.check(time.monotonic(),actual['volts'],actual['temps'],state['gravity'],lease)
        # Bringup requires physical placement within 0.1 rad of home. No blind homing sweep.
        if max(abs(p-h) for p,h in zip(actual['positions'],cal.home))>.1:
            raise RuntimeError('place supported robot within 0.1 rad of calibrated home before arming')
        if Path(args.stop_file).exists(): raise RuntimeError('STOP file present; torque enable refused')
        # Torque remains off: require a stream of actual stable readings, never a sent HOME target.
        settle_deadline=time.monotonic()+2.
        while True:
            if Path(args.stop_file).exists():raise RuntimeError('STOP during measured HOME preflight')
            actual=motors.read();state=imu.read();measured=time.monotonic()
            cmd,mouth,lease=read_command(args.command);context.validate_commands(cmd,mouth)
            power.check();check_joint_currents(actual['current_ma'],cal)
            guard.check(time.monotonic(),actual['volts'],actual['temps'],state['gravity'],lease)
            ready=context.observe(actual['positions'],actual['velocities'],state['gyro'],state['gravity'],measured,time.monotonic(),state['age_s'])
            last_measured=(actual,state,measured)
            if args.telemetry:publish_telemetry(args.telemetry,actual,state,cal.sha256,args.robot_profile,False,measured,motion_context=context.status())
            if ready:break
            if time.monotonic()>=settle_deadline:raise RuntimeError('actual HOME did not remain stable for0.5s within2s')
            time.sleep(.02)
        def arming_ready():
            context.require_fresh(time.monotonic())
            if Path(args.stop_file).exists():raise RuntimeError('STOP during torque enable')
            cmd,mouth,lease=read_command(args.command);context.validate_commands(cmd,mouth)
            power.check()
            guard.check(time.monotonic(),actual['volts'],actual['temps'],state['gravity'],lease)
            context.require_fresh(time.monotonic())
        context.activate(time.monotonic())
        motors.enable(actual['positions'],check_ready=arming_ready)
        power.activate_control()  # Short 50Hz heartbeat starts after bounded torque setup.
        previous_target=actual['positions']; previous_action=[0.]*14
        log=open(args.log,'a',buffering=1); log.write(json.dumps({'event':'armed','calibration_sha256':cal.sha256,'benchmark':bench})+'\n')
        tick=time.monotonic(); next_health=tick; deadline=tick+args.seconds
        while time.monotonic()<deadline:
            start=time.monotonic()
            if Path(args.stop_file).exists(): raise RuntimeError('STOP file present')
            imu_state=imu.read(); imu_read_at=time.monotonic(); sensors=motors.read(); measured_at=time.monotonic()
            imu_state={**imu_state,'age_s':imu_state['age_s']+measured_at-imu_read_at}
            last_measured=(sensors,imu_state,measured_at)
            commands,mouth,lease=read_command(args.command)
            context.observe(sensors['positions'],sensors['velocities'],imu_state['gyro'],imu_state['gravity'],measured_at,time.monotonic(),imu_state['age_s'])
            context.validate_commands(commands,mouth)
            power_state=power.check()
            check_joint_currents(sensors['current_ma'],cal)
            guard.check(time.monotonic(),sensors['volts'],sensors['temps'],imu_state['gravity'],lease)
            if start>=next_health:
                motors.check_health()
                next_health=start+1
            obs=observation(imu_state['gyro'],imu_state['gravity'],sensors['positions'],sensors['velocities'],previous_action,commands,cal.home)
            mouth_joint=cal.joints[9]
            mouth=mouth_step(mouth,previous_target[9],mouth_joint['min_rad'],mouth_joint['max_rad'],mouth_joint['max_step_rad'])
            raw_actions=policy.run(obs);actions,mouth=context.filter_actions(raw_actions,mouth); target=action_targets(actions,mouth,cal.home,cal.data['action_scale'])
            cal.check_step(target,previous_target)
            elapsed=time.monotonic()-start
            if elapsed>.020: raise RuntimeError(f'control computation missed 20ms deadline ({elapsed:.4f}s)')
            motors.write(target);sent_at=time.monotonic();previous_action=raw_actions;previous_target=target
            last_sent={'commands':commands,'mouth_rad':mouth,'monotonic_s':sent_at,'source_monotonic_s':lease}
            if args.telemetry: publish_telemetry(args.telemetry,sensors,imu_state,cal.sha256,args.robot_profile,True,measured_at,last_sent,motion_context=context.status())
            log.write(json.dumps({'t':start,'obs':obs,'actions':raw_actions,'applied_actions':actions,'motion_context':context.status(),'targets':target,'volts':sensors['volts'],
                                  'temps':sensors['temps'],'current_ma':sensors['current_ma'],'imu_age':imu_state['age_s'],
                                  'power':power_state,'cycle_ms':(time.monotonic()-start)*1000})+'\n')
            tick+=.02
            if time.monotonic()>tick: raise RuntimeError('control output/logging missed 20ms deadline')
            time.sleep(max(0,tick-time.monotonic()))
    finally:
        original=sys.exc_info()[1];cleanup=[]
        if power:
            try:power.close()
            except Exception as exc:cleanup.append('RUN_REQ shutdown failed: '+str(exc))
        if motors:
            try:
                failures=motors.torque_off()
                if failures:print('TorqueOff not acknowledged after requested supply cut: '+'; '.join(failures),file=sys.stderr)
            except Exception as exc:cleanup.append('motor cleanup: '+str(exc))
            finally:
                try:motors.close()
                except Exception as exc:cleanup.append('motor port close: '+str(exc))
        if args.telemetry and last_measured:
            try:publish_telemetry(args.telemetry,last_measured[0],last_measured[1],cal.sha256,args.robot_profile,False,last_measured[2],last_sent,motion_context={**context.status(),'active':False,'ready':False})
            except Exception as exc:cleanup.append('telemetry final state: '+str(exc))
        for resource in [log,imu,bus]:
            if resource:
                try:resource.close()
                except Exception as exc:cleanup.append('resource close: '+str(exc))
        if cleanup:raise RuntimeError((str(original)+'; 'if original else '')+'; '.join(cleanup))


def powered_servo_command(args):
    from .power import PowerConfig,PowerSystem
    from .dynamixel import Dynamixels
    c=Calibration.load(args.calibration,motion=False);cfg=PowerConfig.load(args.power_config)
    supply=None;m=None
    try:
        supply=PowerSystem(cfg);supply.start();supply.enable();time.sleep(.2)
        m=Dynamixels(args.serial,c);supply.check()
        if args.mode=='inspect':print(json.dumps(m.inspect(),indent=2))
        else:
            m.commission();supply.check()
            print('Commissioned per-model settings; torque remains off. Power closes on command exit.')
    finally:
        try:
            if supply:supply.close()
        finally:
            if m:
                try:
                    if args.mode=='commission':m.torque_off()
                finally:m.close()


def bench_power_capture(args):
    """Isolated electronic-load calibration only: no actuator transport exists here."""
    from .power import PowerSystem
    from .power_io import ntc_temperature
    if args.confirm_servos_disconnected is not True or isinstance(args.seconds,bool) or not math.isfinite(args.seconds) or not .5<=args.seconds<=5:
        raise ValueError('bench capture requires disconnected servo confirmation and0.5..5s duration')
    if Path(args.stop_file).exists():raise RuntimeError('STOP file present; bench supply refused')
    class NominalBenchOnly:
        data={'measurements_verified':False,'i2c_device':args.i2c,
              'ina226':{n:{'current_gain':1.,'current_offset_A':0.,'bus_gain':1.,'bus_offset_V':0.}for n in ('battery','servo','brake')},
              'adc':{'gain':1.,'offset_V':0.}}
        @staticmethod
        def temperature(name,voltage,excitation):return ntc_temperature(voltage,excitation,10000,10000,3977)
    supply=None;records=[]
    try:
        supply=PowerSystem(NominalBenchOnly());supply.start();deadline=time.monotonic()+args.seconds
        supply.enable();supply.activate_control()
        while time.monotonic()<deadline:
            if Path(args.stop_file).exists():raise RuntimeError('STOP file present')
            row=supply.check()
            if abs(row['power']['servo']['current_A'])>5.:raise RuntimeError('isolated calibration load exceeds5A ceiling')
            records.append(row);time.sleep(min(.02,max(0,deadline-time.monotonic())))
        if not records:raise RuntimeError('no samples before bounded calibration deadline')
        return {'calibrated':False,'motion_approved':False,'source':'live hardware, nominal conversion for isolated load calibration only','servo_bus_physically_disconnected_confirmed':True,'maximum_requested_duration_s':args.seconds,'samples':records}
    finally:
        if supply:supply.close()


def main():
    p=argparse.ArgumentParser(description=__doc__); sub=p.add_subparsers(dest='mode',required=True)
    q=sub.add_parser('check-calibration');q.add_argument('path')
    q=sub.add_parser('imu');q.add_argument('--i2c',required=True);q.add_argument('--address',type=lambda s:int(s,0),default=0x6a)
    q.add_argument('--mount',type=float,nargs=4,required=True,metavar=('W','X','Y','Z'));q.add_argument('--seconds',type=float,default=10)
    q=sub.add_parser('power-diagnostics');q.add_argument('--i2c',required=True)
    q=sub.add_parser('bench-power-capture');q.add_argument('--i2c',required=True);q.add_argument('--confirm-servos-disconnected',action='store_true',required=True)
    q.add_argument('--seconds',type=float,default=2);q.add_argument('--stop-file',default='/tmp/microduck-r8.STOP')
    q=sub.add_parser('commission');hardware_args(q)
    q=sub.add_parser('inspect');hardware_args(q)
    q=sub.add_parser('stop');q.add_argument('--path',default='/tmp/microduck-r8.STOP')
    q=sub.add_parser('command');q.add_argument('--path',default='/tmp/microduck-r8-command.json')
    q.add_argument('--vx',type=float,default=0);q.add_argument('--vy',type=float,default=0);q.add_argument('--yaw',type=float,default=0)
    q.add_argument('--head',type=float,nargs=4,default=[0]*4);q.add_argument('--body',type=float,nargs=3,default=[0]*3)
    q.add_argument('--mouth',type=float,default=0);q.add_argument('--seconds',type=float,default=10)
    q=sub.add_parser('run');hardware_args(q);q.add_argument('--policy',required=True);q.add_argument('--manifest',required=True)
    q.add_argument('--arm',action='store_true');q.add_argument('--command',default='/tmp/microduck-r8-command.json')
    q.add_argument('--stop-file',default='/tmp/microduck-r8.STOP');q.add_argument('--log',default='run.jsonl');q.add_argument('--seconds',type=float,default=10)
    q.add_argument('--motion-context',choices=('head_home_locked','supported_double'),default='head_home_locked')
    q.add_argument('--confirm-supported-double',action='store_true',help='actual dual-foot supported setup; not an automatic contact measurement')
    q.add_argument('--telemetry',help='atomically publish latest actual joint/IMU state for local clients')
    q.add_argument('--robot-profile',default=ROBOT_PROFILE)
    q=sub.add_parser('validate-policy');q.add_argument('path')
    args=p.parse_args()
    if args.mode in ('run','commission','inspect','power-diagnostics','bench-power-capture'):
        def interrupted(*_):raise KeyboardInterrupt
        signal.signal(signal.SIGTERM,interrupted);signal.signal(signal.SIGINT,interrupted)
    if args.mode=='check-calibration':
        c=Calibration.load(args.path,motion=True);print(json.dumps({'calibration_sha256':c.sha256,'motion_gate':'passed'}))
    elif args.mode=='stop':
        Path(args.path).write_text('Operator stop\n');print('Stop requested; confirm torque/power status on hardware.')
    elif args.mode=='command':
        end=time.monotonic()+args.seconds;path=Path(args.path)
        with CommandWriter(path) as writer:
            while time.monotonic()<end:
                data={'monotonic_s':time.monotonic(),'commands':[args.vx,args.vy,args.yaw]+args.head+[0,0]+args.body+[0],'mouth_rad':args.mouth}
                writer.write(data);read_command(path);time.sleep(.05)
    elif args.mode=='imu':
        from .imu import LinuxI2c,Lsm6dsv16x
        bus=LinuxI2c(args.i2c,args.address)
        try:
            imu=Lsm6dsv16x(bus,args.mount);imu.initialize();imu.warmup();end=time.monotonic()+args.seconds
            while time.monotonic()<end: print(json.dumps(imu.read()));time.sleep(.02)
        finally: bus.close()
    elif args.mode in ('commission','inspect'):powered_servo_command(args)
    elif args.mode=='bench-power-capture':print(json.dumps(bench_power_capture(args),indent=2))
    elif args.mode=='power-diagnostics':
        from .power_io import raw_diagnostics
        print(json.dumps(raw_diagnostics(args.i2c),indent=2))
    elif args.mode=='validate-policy':
        from .policy import Policy
        print(json.dumps(Policy(args.path).benchmark(),indent=2))
    else: run(args)


if __name__=='__main__':
    try: main()
    except (ValueError,RuntimeError,OSError,KeyboardInterrupt) as exc:
        print(f'STOPPED: {exc}',file=sys.stderr);sys.exit(2)

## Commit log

2026-09-13 Publish verified Microduck R20 structure, R21 simulation and R13 electronics baseline
    [BOM.csv, BOM_JLC.csv, BOM_R13_CM4_Carrier.csv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]
2026-09-13 Publish R22 compact power engineering candidate and verification artifacts
    [BOM_R22.csv, BOM_R22_Entry.csv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]
2026-09-22 Publish R23 integrated power mechanical and harness design review
    [complete-conductor-cut-table.csv, part-catalog.csv]
2026-09-22 Add Microduck-style removable head camera cover and R24 design checks
    [BOM.csv, black-camera-eye-bezel.3mf, front-face-camera-carrier.3mf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]
2026-09-22 Add bottom-entry head harness and refresh OpenDuck homepage
    [R25_lower_head_shell_bottom_entry.3mf, R25_top_head_shell_closed_side.3mf, bottom-entry-bridge.step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]
2026-09-24 docs: add English overview and measured leg proportion study
2026-09-24 Add R26 cover-first thigh design and verified complete assembly
    [R26_L_thigh_short_cover.3mf, R26_L_thigh_short_cover.step, R26_L_thigh_short_cover.stl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]
2026-09-28 Publish R29 interference and mass-resolved gait candidate
    [R29_lower_head_shell_mouth_10deg_3mm.3mf, R29_lower_head_shell_mouth_10deg_3mm.ply, R29_neck_lower_P5_PEEK_exit_lip.step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]
